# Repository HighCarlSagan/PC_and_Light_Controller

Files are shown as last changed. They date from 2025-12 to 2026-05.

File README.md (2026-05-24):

# PC & Light Controller







A single-board ESP32 controller that remotely actuates a PC's UPS power button via servo and switches three 5 V LED lighting channels via eFuses — all driven from a Telegram bot. Part of a larger homelab automation setup.

<p align="center">
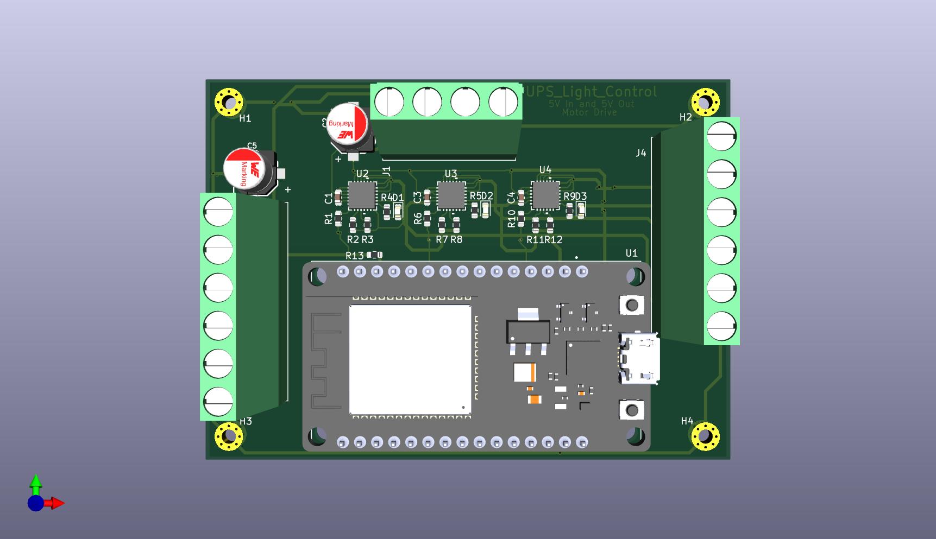
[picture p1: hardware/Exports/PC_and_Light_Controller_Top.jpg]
PCB top render
  
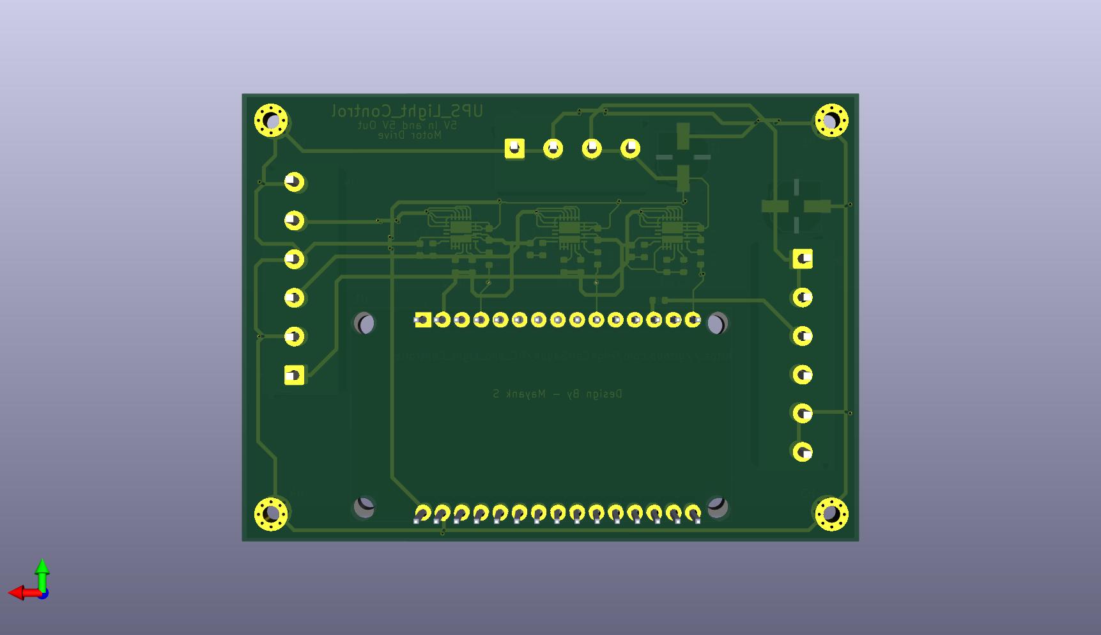
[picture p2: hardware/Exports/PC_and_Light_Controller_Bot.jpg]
PCB bottom render
  
</p>

---

## Why I Built This

I needed a physical "finger" to press the UPS power button on my desk so I could wake the PC from anywhere — usually while travelling, sometimes just from another room — without opening the UPS chassis (which would void warranty) and without buying a generic smart-plug solution that wouldn't fit cleanly into the rest of my homelab.

This board is the missing piece in a longer chain: once the UPS is on, my homelab handles the rest — Wake-on-LAN brings up the PC, Tailscale + SSH let me into the machine, and Home Assistant takes care of the rest of the room. The UPS button was the one stubbornly physical step left, and the LEDs were a natural extension once I had an ESP32 sitting there with spare GPIOs and a free 5 V rail.

A few things I deliberately wanted out of the project:

- **Telegram bot integration without port forwarding** — the ESP32 polls outbound, no inbound ports exposed
- **No new cloud dependency beyond Telegram** — everything else stays local to the homelab
- **Clean integration with my existing 5 V/3.3 V bench supply** — no extra wall-warts
- **A learning project for ESP32 + eFuse load switching** — TPS259807 with proper ILIM configuration

---

## Initial Requirements

| # | Requirement | Target | Outcome |
|---|---|---|---|
| 1 | UPS power-button actuation | Non-invasive, preserves warranty | Servo-actuated push (no electrical mod to UPS) |
| 2 | LED channels | 3 independently switched 5 V loads | 3× TPS259807 eFuse channels |
| 3 | Per-channel current | ≥ 0.5 A per channel | ILIM set to 1 A per channel (headroom) |
| 4 | Remote control | Internet-reachable, no port forwarding | Outbound Telegram bot polling |
| 5 | Security | Only authorized user can issue commands | Chat ID allowlist verification |
| 6 | Homelab integration | Works alongside WoL + SSH workflow | Sits as the "physical actuator" tier |
| 7 | Power | Powered from existing dual-rail bench PSU | Single 5 V input |
| 8 | MCU count | Single board, single MCU | One ESP32 DevKit V1 doing both jobs |
| 9 | Variable per-channel current limit | Set in firmware/UI | **V1 has fixed 1 A** — V2 will use software-trim ILIM |
| 10 | Local fallback (LAN-only mode) | Optional | Not in V1 — Telegram-only for now |

---

## Specifications

| Parameter | Value |
|---|---|
| MCU | ESP32 DevKit V1 (ESP-WROOM-32) |
| Input voltage | 5 V DC |
| Light channels | 3× TPS259807 eFuse, ILIM = 1 A each |
| Servo output | 1× PWM (5 V tolerant) |
| Status indicators | 3× per-channel LEDs |
| PCB | 2-layer FR-4, 1.6 mm |
| Connectors | 1× 4-pin power input, 2× 6-pin output blocks |
| Mounting | 4× corner holes |
| Communication | WiFi 802.11 b/g/n + outbound HTTPS to Telegram |

---

## Architecture

```
                                   ┌──────────────────┐
   Telegram Cloud  ◀──HTTPS poll──▶│   ESP32 DevKit   │
                                   │   (single MCU)   │
                                   └──┬─────┬─────┬───┘
                                      │     │     │
            GPIO ──────┬───────┬──────┘     │     │
                       │       │            │     │
                  ┌────▼─┐ ┌───▼──┐ ┌───────▼──┐  │
                  │ EN1  │ │ EN2  │ │   EN3    │  │  PWM
                  │TPS1  │ │TPS2  │ │   TPS3   │  │   │
                  │259807│ │259807│ │  259807  │  │   ▼
                  └──┬───┘ └──┬───┘ └────┬─────┘  │  Servo
                     │        │          │        │   │
                  Light 1  Light 2    Light 3     │   ▼
                                                  │  UPS button
                                                  └─ (mechanical press)
```

A single ESP32 polls the Telegram bot every ~1 second, parses incoming commands, and dispatches to either:

- **GPIO outputs** driving the EN pins of three TPS259807 eFuses (light channels), or
- **A PWM channel** driving a servo whose horn physically presses the UPS power button.

Per-channel status LEDs reflect the current state of each light. A chat-ID allowlist in firmware ensures only authorized users can issue commands.

---

## Why a Servo for the UPS Button?

This is the unusual design choice and worth calling out: most projects that automate a button-press would either tap directly across the button contacts with a transistor, or use a relay. Both work — neither was acceptable here.

The UPS is still under warranty. Opening it to solder anything across the button contacts would void that. A servo with a 3D-printed horn pressing the button externally is fully non-invasive — the UPS sees nothing electrically unusual, the warranty stays intact, and the same approach generalizes to any push-button I might want to actuate later (microwave, doorbell, whatever). It's a slightly larger mechanical solution, but mechanically and electrically clean.

---

## Key Components

| Reference | Part | Function |
|---|---|---|
| U1 | ESP32 DevKit V1 | WiFi + dual-core MCU, both controllers in one |
| U2, U3, U4 | TI TPS259807ONRGER | 5 V eFuse load switches with adjustable current limit |
| D1, D2, D3 | LEDs (0603) | Per-channel status indicators |
| C2, C5 | 100 µF / 16 V | Bulk decoupling on input + output |
| C1, C3, C4 | 0.1 µF / 16 V | Local decoupling at each TPS259807 |
| R1/R6/R10 | 220 Ω | LED current limiting |
| R2/R7/R11 | 298 Ω | TPS259807 ILIM resistor (sets ~1 A current limit) |
| R3/R8/R12 | 10 kΩ | TPS259807 EN pull-down |
| R4/R5/R9/R13 | 1 kΩ | GPIO series resistors / servo signal |
| J1 | 4-pin screw terminal | 5 V power input from external PSU |
| J3, J4 | 6-pin screw terminals | Light output channels + servo header |

---

## Connector Pinout

| Connector | Function |
|---|---|
| J1 | 5 V input from external PSU (V+, V+, GND, GND) |
| J3 | Light outputs (channels 1–3) — V+ and GND pairs per channel |
| J4 | Servo header + auxiliary outputs |

> Detailed pin-by-pin assignments are on the PCB silkscreen and in `hardware/Exports/schematic.pdf`.

---

## Firmware

### Architecture

Single firmware image runs on one ESP32 and serves both the UPS-press and lights-switching commands. Internally the code is split into two logical modules under separate folders so the unit-tests stay focused, but only one binary gets flashed.

| Layer | Library / Framework |
|---|---|
| Build system | PlatformIO |
| Framework | Arduino-ESP32 |
| Networking | WiFi.h + WiFiClientSecure |
| Telegram client | UniversalTelegramBot |
| Servo control | ESP32Servo |
| JSON parsing | ArduinoJson |

### Command interface

Commands are split by prefix so both function groups remain logically separate:

**UPS commands** (servo actuation):
- `/ups_press` — Press the UPS power button
- `/ups_status` — Get controller status
- `/ups_help` — Show help

**Lights commands**:
- `/lights_<n>_on`, `/lights_<n>_off` — Control individual light (n = 1, 2, 3)
- `/lights_all_on`, `/lights_all_off` — Bulk control
- `/lights_status` — Report current state of all channels
- `/lights_help` — Show help

Full command reference: [`docs/commands/TELEGRAM_COMMANDS.md`](docs/commands/TELEGRAM_COMMANDS.md)

### Security

- **Chat ID allowlist** — only pre-registered Telegram chat IDs are honored, all others ignored
- **Outbound-only networking** — no inbound ports, no port forwarding, no exposed services on the LAN
- **TLS to Telegram** — all command traffic over HTTPS
- **Secrets isolation** — WiFi credentials, bot token, and chat IDs live in `secrets.h`, gitignored, with an `.example` template committed

### Repository layout for firmware

```
firmware/
├── ups-controller/                 # UPS servo logic (build target 1)
│   ├── include/
│   │   ├── config.h                # Pin assignments, timing constants
│   │   ├── secrets.h               # GITIGNORED — actual credentials
│   │   └── secrets.h.example       # Template
│   ├── src/main.cpp
│   └── platformio.ini
└── lights-controller/              # LED switching logic (build target 2)
    ├── include/                    # Same structure as above
    ├── src/main.cpp
    └── platformio.ini
```

> The two folders compile to two separate firmware images in the V1 development setup. For deployment, both feature sets will be merged into a single combined firmware image for the production ESP32 — that consolidation is part of the deployment step.

---

## Setup & Deployment

> **Status:** PCB delivered, awaiting assembly. Step-by-step setup will be added here once the board is soldered, flashed, and deployed in the rack.

This section will cover:

1. Bill of materials acquisition
2. SMD + through-hole assembly notes
3. ESP32 first-flash procedure
4. Telegram bot creation (BotFather workflow)
5. Configuring `secrets.h` (WiFi, bot token, chat ID allowlist)
6. Initial bringup test sequence (status LED check, channel-by-channel test, servo calibration)
7. Mounting and mechanical alignment of the servo to the UPS button
8. Integration into the homelab rack and final cabling

---

## Testing

> Test results will be added in `docs/images/` and a summary table here once bringup is complete.

### Planned bringup test sequence

| Step | Test | Pass criteria |
|---|---|---|
| 1 | Visual inspection | No solder bridges, all parts present, polarized parts oriented correctly |
| 2 | Power-on, no firmware | 5 V rail clean, no smoke, current draw < 50 mA at idle |
| 3 | Firmware flash | ESP32 enumerates, serial console prints boot banner |
| 4 | WiFi association | Connects to configured SSID, IP assigned |
| 5 | Telegram heartbeat | Bot responds to `/lights_help` and `/ups_help` |
| 6 | Light channel test (no load) | Each EN GPIO toggles its eFuse; status LED follows; no output current with no load attached |
| 7 | Light channel test (with load) | Each channel drives an LED strip up to ~0.5 A; status LED on; eFuse cool |
| 8 | Light channel overcurrent test | Force ~1.2 A on one channel, eFuse trips, channel recovers after re-enable |
| 9 | Servo sweep | Manual `/ups_press` triggers full press-and-release cycle, audible click on UPS |
| 10 | Soak test | All three lights on + occasional servo press, 1 hour, no thermal issues |

### Results

*To be filled in after bringup.*

---

## Hardware

### PCB

- 2-layer FR-4
- 1.6 mm thickness
- 1 oz copper
- ENIG or HASL lead-free
- Designed in KiCad 9.0
- Compatible with JLCPCB, PCBWay, OSHPark, etc.

### Manufacturing files

- Gerbers + drill files: [`hardware/Exports/Gerbers/`](hardware/Exports/Gerbers/)
- Zipped gerbers (drag-and-drop into fab portals): `hardware/Exports/pc_and_light_controller_gerbers.zip`
- Interactive BOM: `hardware/Exports/ibom.html`
- BOM CSV: `hardware/Exports/UPS_Switch_BoM.csv`
- Schematic PDF: `hardware/Exports/schematic.pdf`

---

## Repository Structure

```
PC_and_Light_Controller/
├── docs/
│   ├── commands/
│   │   └── TELEGRAM_COMMANDS.md         # Full command reference
│   ├── Flashing_Guide_Mini.md           # ESP32 flash quick reference
│   ├── images/                          # Photos & screenshots
│   └── pinout.ini                       # Pin assignment reference
├── firmware/
│   ├── ups-controller/                  # Servo / UPS button firmware module
│   └── lights-controller/               # Lights / eFuse firmware module
├── hardware/
│   ├── Exports/                         # Gerbers, BOM, renders, schematic
│   ├── Libraries/                       # Custom KiCad symbols, footprints, 3D models
│   ├── PC_and_Light_Controller.kicad_pro
│   ├── PC_and_Light_Controller.kicad_sch
│   └── PC_and_Light_Controller.kicad_pcb
├── enclosure/
│   └── docs/                            # FreeCAD / Blender enclosure work
├── LICENSE
└── README.md
```

---

## When to Use This

**Good fit:**
- Remote-pressing a physical button you can't or won't open
- Switching small 5 V DC loads (LED strips, fans, low-power lighting) with overcurrent protection
- Building blocks for a homelab automation tier where outbound-only networking is desired
- A learning vehicle for ESP32 + Telegram + eFuse load switching

**Not a good fit:**
- Mains-voltage switching (use a proper relay board with isolation)
- High-current loads above ~1 A per channel (the V1 ILIM cap)
- Time-critical control where ~1 second polling latency matters
- Air-gapped networks (V1 is Telegram-dependent — V2 will add a local-only path)

---

## Roadmap

### V1 (current)
- ✅ Hardware design complete
- ✅ Firmware logic written and tested on dev boards
- 🔄 PCB assembly pending
- 🔄 First-deployment bringup pending

### V2 wishlist
- Variable per-channel current limit (digitally trimmable ILIM)
- Local-only control path (MQTT to homelab broker, Telegram becomes one of multiple frontends)
- Per-channel current measurement (INA-class shunt monitor) for telemetry back to homelab
- Combined unified firmware image instead of two-folder dev split
- Onboard 5 V regulation so the board can be powered from a wider input range
- Status display (small OLED) showing channel state and last command

---

## Security Note

This board exists inside a private homelab network and is gated by a Telegram chat-ID allowlist. As deployed:

- Network-side identifiers (SSID, IPs, MACs) are intentionally **not** committed to this repo
- All credentials live in `secrets.h` files which are gitignored — only `.example` templates ship
- The Telegram bot token is the principal credential; treat it like a password

If you fork this and deploy it on your own network, replace every value in `secrets.h.example` with your own and never commit a real `secrets.h`.

---

## License

- **Hardware**: [CERN-OHL-P-2.0](LICENSE) (Permissive)
- **Firmware**: MIT

---

## Related Projects

- [Dual_Power_Supply](https://github.com/HighCarlSagan/Dual_Power_Supply) — provides the 5 V rail that powers this board
- [Carls_Homelab](https://github.com/HighCarlSagan/Carls_Homelab) — the rest of the homelab stack this integrates with

---

## Author

**Mayank S (HighCarlSagan)** — [GitHub @HighCarlSagan](https://github.com/HighCarlSagan) · [highcarlsagan.dev](https://highcarlsagan.dev)

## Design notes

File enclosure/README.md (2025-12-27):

# Enclosure Design

FreeCAD designs for the PC & Light Controller enclosure.

## Files

- `freecad/` - FreeCAD project files (.FCStd)
- `stl/` - 3D printable STL files
- `step/` - STEP files for CNC/sharing
- `docs/` - Assembly instructions, dimensions

## Design Requirements

- Mount for custom PCB
- Cutouts for:
  - Power input connector
  - 3x LED output connectors
  - Motor output connector
  - USB programming port (ESP32)
- Ventilation for components
- Mounting holes for installation

## Printing Settings

TBD - will update after first prototype

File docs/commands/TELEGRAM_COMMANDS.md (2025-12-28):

# Telegram Bot Commands

This document lists all available commands for the PC & Light Controller Telegram bot.

## Bot Information
- **Bot Name:** [Your bot name]
- **Bot Username:** @[your_bot_username]
- **Security:** Only responds to authorized Chat ID

## UPS Controller Commands

Control the UPS power button via servo motor.

| Command | Description |
|---|---|
| `/ups_press` | Press the UPS power button (servo activates for 500ms) |
| `/ups_status` | Get UPS controller status (WiFi, IP, servo state) |
| `/ups_help` | Show UPS controller help |

**Example Usage:**
```
/ups_press
```
Response: `✅ UPS button pressed!`

---

## Lights Controller Commands

Control 3 LED light switches.

### Individual Light Control

| Command | Description |
|---|---|
| `/lights_1_on` | Turn Light 1 ON |
| `/lights_1_off` | Turn Light 1 OFF |
| `/lights_2_on` | Turn Light 2 ON |
| `/lights_2_off` | Turn Light 2 OFF |
| `/lights_3_on` | Turn Light 3 ON |
| `/lights_3_off` | Turn Light 3 OFF |

### Bulk Control

| Command | Description |
|---|---|
| `/lights_all_on` | Turn all lights ON |
| `/lights_all_off` | Turn all lights OFF |

### Status & Help

| Command | Description |
|---|---|
| `/lights_status` | Get status of all lights + WiFi info |
| `/lights_help` | Show lights controller help |

**Example Usage:**
```
/lights_1_on
```
Response: `✅ Light 1 ON`
```
/lights_status
```
Response:
```
💡 Lights Status:
Light 1: ON ✓
Light 2: OFF
Light 3: OFF
WiFi: Connected ✓
IP: 192.168.0.84
```

---

## How It Works

### Architecture
- **One Telegram Bot** controls both ESP32 devices
- **Command Prefixes** determine which ESP32 responds:
  - `/ups_*` → UPS Controller ESP32
  - `/lights_*` → Lights Controller ESP32
- Each ESP32 ignores commands not meant for it

### Security
- Only authorized Chat ID can send commands
- Unauthorized users receive "⛔ Unauthorized access" message
- All commands are logged to serial monitor

### Response Time
- Commands are checked every 1 second (polling interval)
- Typical response time: 1-2 seconds

---

## Troubleshooting

**Bot not responding:**
1. Check ESP32 is powered on
2. Check WiFi connection (LED should be solid ON)
3. Check serial monitor for errors
4. Verify bot token and chat ID in `secrets.h`

**Wrong device responding:**
- Check command prefix (`/ups_` vs `/lights_`)
- Each ESP32 only responds to its prefix

**Unauthorized access message:**
- Verify your Chat ID matches the one in `secrets.h`
- Get your Chat ID from @userinfobot

---

## Adding More Devices

To add another ESP32 device:

1. Choose a new command prefix (e.g., `/garage_`)
2. Create new firmware folder
3. Use same bot token and chat ID
4. Check for prefix in `handleNewMessages()`

Example for garage door:
```cpp
if (!text.startsWith("/garage_")) {
  return; // Ignore
}
```

---

## Notes

- Both ESP32s use the **same WiFi network**
- Both ESP32s use the **same Telegram bot**
- Commands work from anywhere in the world (via Telegram)
- No port forwarding required
- No separate server needed

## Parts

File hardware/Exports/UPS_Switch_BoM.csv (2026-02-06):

Reference | Qty | Value | DNP | Exclude from BOM | Exclude from Board | Footprint | Datasheet | Manufacturer | Price | Description | Manufacturer Part Number | Vendor | Vendor Link | Vendor Part Number
C1,C3,C4 | 3 | 0.1u_16V_0603 |  |  |  | Capacitor_SMD:C_0603_1608Metric | https://www.yageo.com/en/Chart/Download/pdf/CC0603KRX7R7BB104 | YAGEO | 7 | 0.1 µF ±10% 16V Ceramic Capacitor X7R 0603 (1608 Metric) | CC0603KRX7R7BB104 |  | https://www.digikey.in/en/products/detail/yageo/CC0603KRX7R7BB104/302822 | 311-1088-1-ND
C2,C5 | 2 | 100u_16V_0603 |  |  |  | ESP32_Devkit_V1:WCAP-ASLI_6.3X5.5_DXL_ | https://www.we-online.com/components/products/datasheet/865080343009.pdf | Würth Elektronik | 24 | 100 µF 16 V Aluminum Electrolytic Capacitors Radial, Can - SMD 2000 Hrs @ 105°C | 865080343009 |  | https://www.digikey.in/en/products/detail/w%C3%BCrth-elektronik/865080343009/5728014 | 732-8419-1-ND
D1,D2,D3 | 3 | LED |  |  |  | LED_SMD:LED_0603_1608Metric | ~ |  |  | Light emitting diode
H1,H2,H3,H4 | 4 | MountingHole_Pad |  | Excluded from BOM |  | MountingHole:MountingHole_2.2mm_M2_Pad_Via | ~ |  |  | Mounting Hole with connection
J1 | 1 | Screw_Terminal_01x04 |  |  |  | TerminalBlock_Phoenix:TerminalBlock_Phoenix_MKDS-1,5-4-5.08_1x04_P5.08mm_Horizontal | ~ |  |  | Generic screw terminal, single row, 01x04, script generated (kicad-library-utils/schlib/autogen/connector/)
J3,J4 | 2 | Screw_Terminal_01x06 |  |  |  | TerminalBlock_Phoenix:TerminalBlock_Phoenix_MKDS-1,5-6-5.08_1x06_P5.08mm_Horizontal | ~ |  |  | Generic screw terminal, single row, 01x06, script generated (kicad-library-utils/schlib/autogen/connector/)
R1,R6,R10 | 3 | 220R_0.21W_0603 |  |  |  | Resistor_SMD:R_0603_1608Metric | https://www.te.com/usa-en/product-2176177-3.datasheet.pdf | TE Connectivity Passive Product | 8 | 220 Ohms ±1% 0.2W, 1/5W Chip Resistor 0603 (1608 Metric) Automotive AEC-Q200 Thick Film | CRGH0603F220R |  | https://www.digikey.in/en/products/detail/te-connectivity-passive-product/CRGH0603F220R/7495060 | 1712-CRGH0603F220RCT-ND
R2,R7,R11 | 3 | 298R_0.21W_0603 |  |  |  | Resistor_SMD:R_0603_1608Metric | https://industrial.panasonic.com/cdbs/www-data/pdf/RDM0000/AOA0000C328.pdf | Panasonic Electronic Components | 14 | 300 Ohms ±0.1% 0.2W, 1/5W Chip Resistor 0603 (1608 Metric) Automotive AEC-Q200 Thick Film | ERJ-PB3B3000V |  | https://www.digikey.in/en/products/detail/panasonic-electronic-components/ERJ-PB3B3000V/6212693 | P19910CT-ND
R3,R8,R12 | 3 | 10k_0.1W_0603 |  |  |  | Resistor_SMD:R_0603_1608Metric | https://industrial.panasonic.com/cdbs/www-data/pdf/RDM0000/AOA0000C328.pdf | Panasonic Electronic Components | 14 | 10 kOhms ±0.1% 0.2W, 1/5W Chip Resistor 0603 (1608 Metric) Automotive AEC-Q200 Thick Film | ERJ-PB3B1002V |  | https://www.digikey.in/en/products/detail/panasonic-electronic-components/ERJ-PB3B1002V/6212869 | P20086CT-ND
R4,R5,R9,R13 | 4 | 1k_0.2W_0603 |  |  |  | Resistor_SMD:R_0603_1608Metric | https://industrial.panasonic.com/cdbs/www-data/pdf/RDM0000/AOA0000C328.pdf | Panasonic Electronic Components | 14 | 1 kOhms ±0.1% 0.2W, 1/5W Chip Resistor 0603 (1608 Metric) Automotive AEC-Q200 Thick Film | ERJ-PB3B1001V |  | https://www.digikey.in/en/products/detail/panasonic-electronic-components/ERJ-PB3B1001V/6212755 | P19972CT-ND
U1 | 1 | ESP32-DEVKIT-V1 |  |  |  | Footprints:MODULE_ESP32_DEVKIT_V1 |  | Jellybean | 400 | ESP32 Devkit Module |  |  | https://robu.in/product/esp32-38pin-development-board-wifibluetooth-ultra-low-power-consumption-dual-core/ | ESP32-DEVKIT-V1
U2,U3,U4 | 3 | TPS259807ONRGER |  |  |  | TPS25980_footprints:VQFN24_RGE_TEX | https://www.ti.com/lit/gpn/tps25980 | Texas Instruments | 196 | Hot Swap Controller 1 Channel General Purpose 24-VQFN (4x4) | TPS259807ONRGER |  | https://www.digikey.com/en/products/detail/texas-instruments/TPS259807ONRGER/13174056 | 296-TPS259807ONRGERCT-ND

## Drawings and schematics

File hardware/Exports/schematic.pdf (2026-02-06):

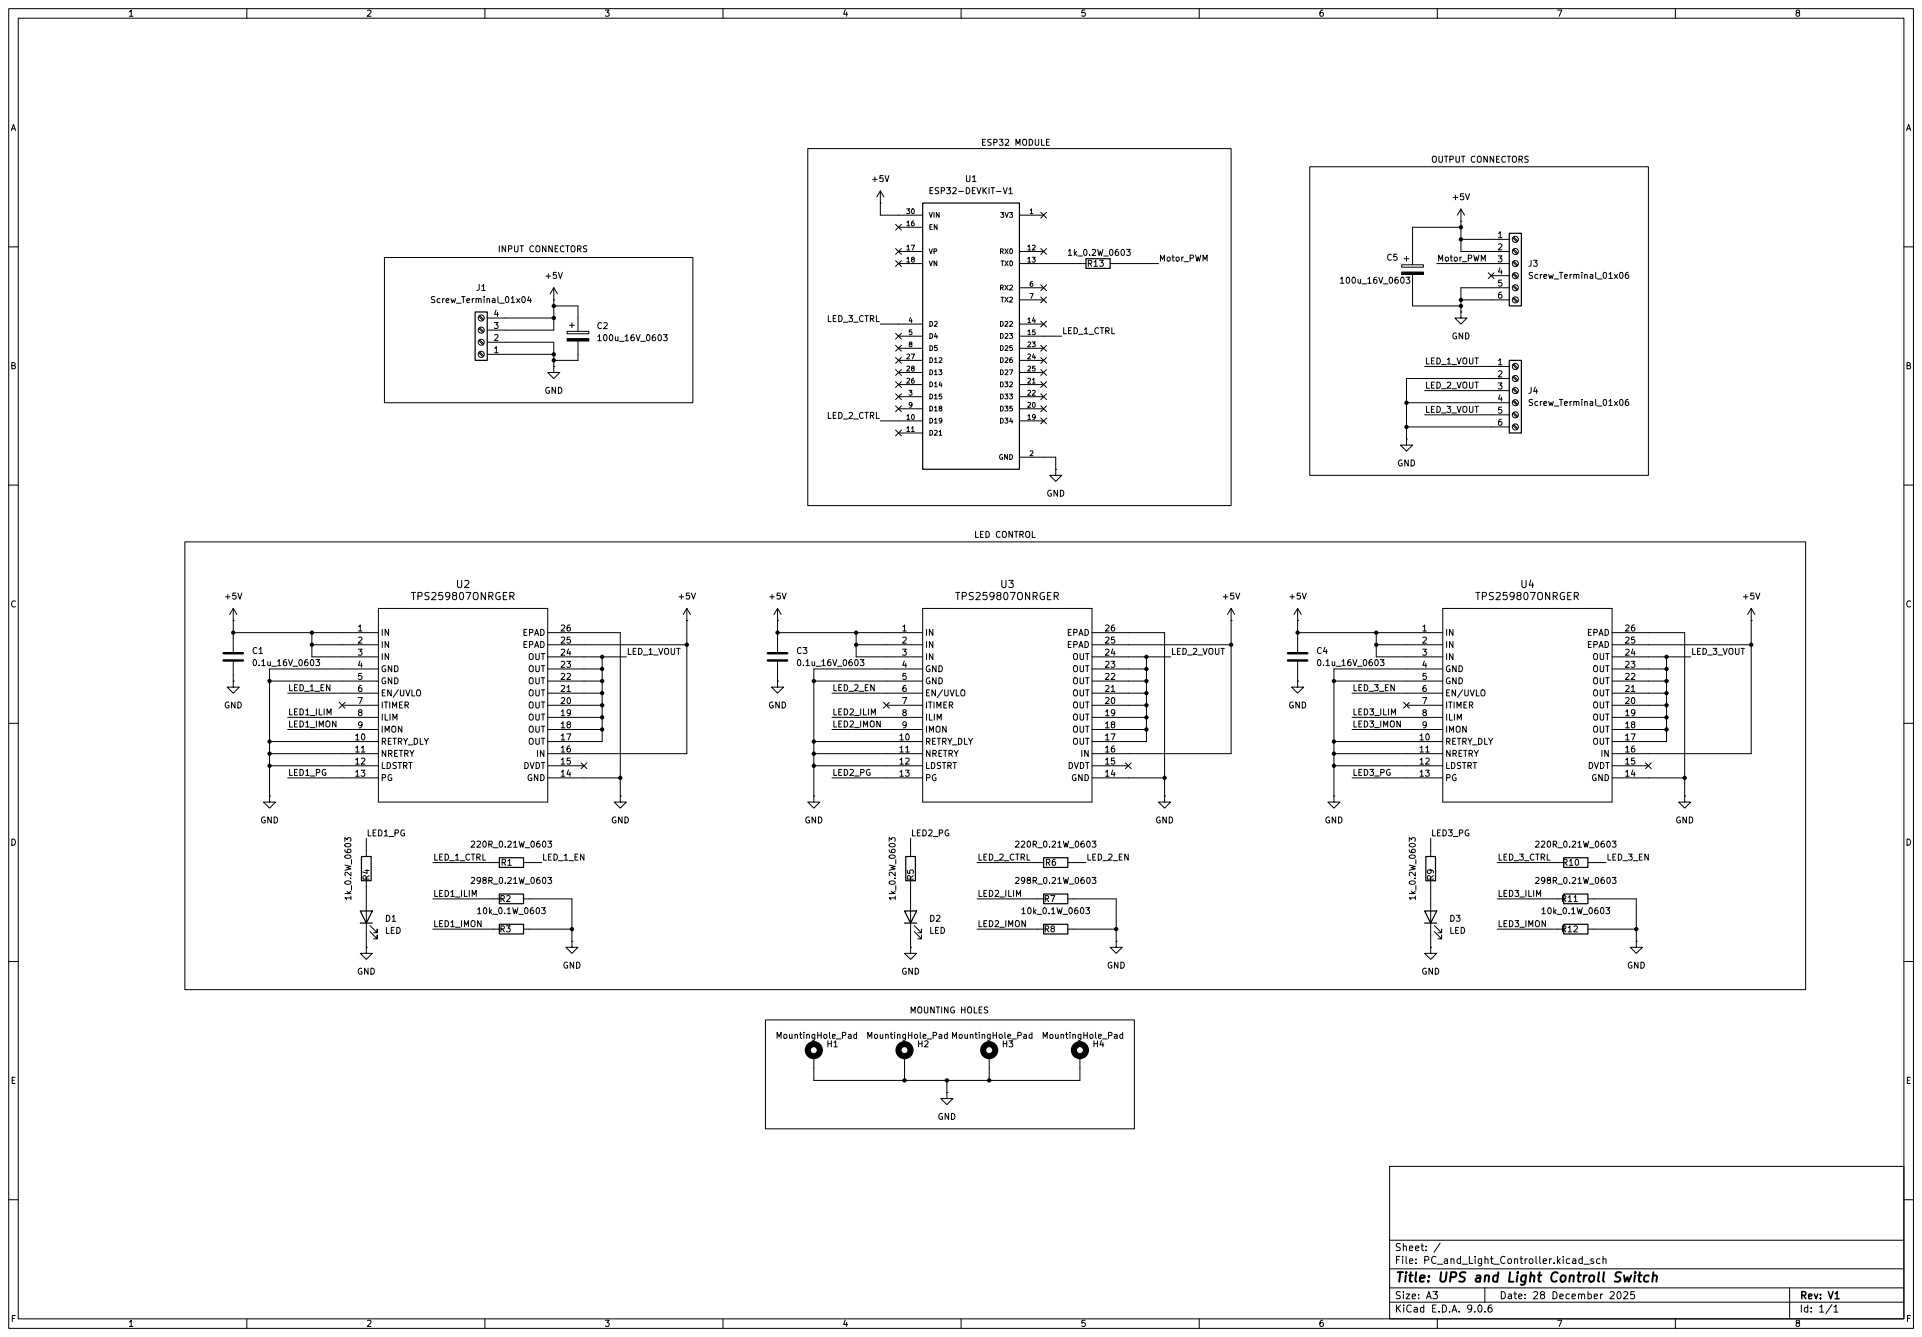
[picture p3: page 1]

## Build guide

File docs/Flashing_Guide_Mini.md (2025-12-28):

ESP32 QUICK FLASH GUIDE - PC & LIGHT CONTROLLER
================================================

HARDWARE SETUP
--------------
ESP32 #1: "UPS"     → Controls servo motor (GPIO 13)
ESP32 #2: "LIGHTS"  → Controls 3 switches (GPIO 25, 26, 27)

Both use:
- WiFi: WIFI_SSID
- Same Telegram bot token
- Same Chat ID: 408698756

FLASH ESP32 #1 (UPS CONTROLLER)
--------------------------------

1. Label board with "UPS" (permanent marker)

2. Connect USB and verify
   lsusb | grep CP210
   ls /dev/ttyUSB*

3. Navigate to firmware
   cd ~/Projects/Hardware/PC_and_Light_Controller/firmware/ups-controller

4. Verify secrets.h exists
   cat include/secrets.h
   (Should show WiFi credentials, bot token, chat ID)

5. Compile and upload
   pio run --target clean
   pio run --target upload
   HOLD BOOT button when you see "Connecting..."

6. Monitor output
   pio device monitor

   Expected output:
   === UPS Controller - Telegram Bot ===
   ✓ Servo initialized
   ✓ WiFi connected!
   IP address: 192.168.0.XX  ← Note this down
   Listening for /ups_ commands...

7. Test from Telegram
   Send: /ups_help
   Should get command list reply

8. Unplug ESP32 #1

FLASH ESP32 #2 (LIGHTS CONTROLLER)
-----------------------------------

1. Label board with "LIGHTS"

2. Connect USB (ESP32 #1 should be unplugged)
   lsusb | grep CP210

3. Navigate to firmware
   cd ~/Projects/Hardware/PC_and_Light_Controller/firmware/lights-controller

4. Verify secrets.h (copy from UPS if missing)
   cat include/secrets.h

5. Compile and upload
   pio run --target clean
   pio run --target upload
   HOLD BOOT when "Connecting..."

6. Monitor output
   pio device monitor

   Expected output:
   === Lights Controller - Telegram Bot ===
   ✓ LED pins initialized
   ✓ WiFi connected!
   IP address: 192.168.0.YY  ← Note this down
   Listening for /lights_ commands...

7. Test from Telegram
   Send: /lights_help
   Should get command list reply

TEST BOTH TOGETHER
------------------

1. Plug in both ESP32s (via USB or 5V power)

2. Test command isolation
   Send: /ups_press      → Only UPS responds
   Send: /lights_1_on    → Only Lights responds

   ✅ Each ESP32 ignores commands not meant for it

TROUBLESHOOTING
---------------

Upload fails (Connecting......):
  Hold BOOT button on ESP32 during upload
  Or: sudo chmod 666 /dev/ttyUSB0

WiFi won't connect:
  Check secrets.h has correct credentials
  Verify WiFi is 2.4GHz (ESP32 doesn't do 5GHz)
  Move ESP32 closer to router

Serial monitor shows garbage:
  pio device monitor -b 115200

Bot not responding:
  Verify Chat ID is 408698756 in secrets.h
  Verify bot token is correct
  Check serial monitor for "Unauthorized user"

QUICK REFERENCE
---------------

Check USB:        lsusb | grep CP210
UPS firmware:     cd ~/Projects/.../firmware/ups-controller
Lights firmware:  cd ~/Projects/.../firmware/lights-controller
Upload:           pio run --target upload (hold BOOT)
Monitor:          pio device monitor (Ctrl+C to exit)

CONFIGURATION RECORD
--------------------

ESP32 #1 (UPS):
  IP Address: _______________
  Commands: /ups_press, /ups_status, /ups_help
  GPIO: 13 (Servo)

ESP32 #2 (Lights):
  IP Address: _______________
  Commands: /lights_1_on, /lights_all_off, /lights_status
  GPIO: 25, 26, 27 (Switches)

WHAT'S NEXT
-----------

1. ✅ Both ESP32s flashed and tested
2. Get servo motor (SG90) and test with /ups_press
3. Get TPS259807 chips for actual switch control
4. Design PCBs in KiCad
5. Order and assemble custom boards

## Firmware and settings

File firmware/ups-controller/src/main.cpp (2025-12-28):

#include <Arduino.h>
#include <WiFi.h>
#include <WiFiClientSecure.h>
#include <UniversalTelegramBot.h>
#include <ESP32Servo.h>
#include "config.h"
#include "secrets.h"

// Function declarations
void handleNewMessages(int numNewMessages);
void pressButton();

// WiFi and Telegram
WiFiClientSecure secured_client;
UniversalTelegramBot bot(BOT_TOKEN, secured_client);

// Servo
Servo upsServo;

// Timing
unsigned long lastBotCheck = 0;

// State
bool isPressed = false;

void setup() {
  Serial.begin(115200);
  delay(1000);
  Serial.println("\n\n=== UPS Controller - Telegram Bot ===");
  
  // Setup pins
  pinMode(STATUS_LED, OUTPUT);
  digitalWrite(STATUS_LED, LOW);
  
  // Attach servo
  upsServo.attach(SERVO_PIN);
  upsServo.write(SERVO_REST_ANGLE);
  Serial.println("✓ Servo initialized at rest position");
  
  // Connect to WiFi
  Serial.print("Connecting to WiFi: ");
  Serial.println(WIFI_SSID);
  WiFi.begin(WIFI_SSID, WIFI_PASSWORD);
  
  while (WiFi.status() != WL_CONNECTED) {
    delay(500);
    Serial.print(".");
  }
  
  Serial.println("\n✓ WiFi connected!");
  Serial.print("IP address: ");
  Serial.println(WiFi.localIP());

  // Skip SSL certificate validation
  secured_client.setInsecure();
  
  // Configure SSL certificate (for Telegram)
  // secured_client.setCACert(TELEGRAM_CERTIFICATE_ROOT);
  
  Serial.println("✓ Telegram bot ready");
  Serial.println("Authorized Chat ID: " + String(CHAT_ID));
  Serial.println("\nListening for /ups_ commands...\n");
  
  // LED on = ready
  digitalWrite(STATUS_LED, HIGH);
}

void loop() {
  // Check for new messages every BOT_CHECK_INTERVAL
  if (millis() - lastBotCheck > BOT_CHECK_INTERVAL) {
    int numNewMessages = bot.getUpdates(bot.last_message_received + 1);
    
    while (numNewMessages) {
      handleNewMessages(numNewMessages);
      numNewMessages = bot.getUpdates(bot.last_message_received + 1);
    }
    
    lastBotCheck = millis();
  }
}

void handleNewMessages(int numNewMessages) {
  for (int i = 0; i < numNewMessages; i++) {
    String chat_id = String(bot.messages[i].chat_id);
    String text = bot.messages[i].text;
    String from_name = bot.messages[i].from_name;
    
    Serial.println("Message from: " + from_name + " (" + chat_id + ")");
    Serial.println("Text: " + text);
    
    // Security: Only respond to authorized user
    if (chat_id != CHAT_ID) {
      Serial.println("⚠️  Unauthorized user! Ignoring.");
      bot.sendMessage(chat_id, "⛔ Unauthorized access");
      continue;
    }
    
    // Only process commands starting with /ups_
    if (!text.startsWith("/ups_")) {
      Serial.println("Not for UPS controller, ignoring.");
      continue;
    }
    
    // Blink LED to show processing
    digitalWrite(STATUS_LED, LOW);
    delay(100);
    digitalWrite(STATUS_LED, HIGH);
    
    // Process commands
    if (text == "/ups_press") {
      pressButton();
      bot.sendMessage(chat_id, "✅ UPS button pressed!");
      
    } else if (text == "/ups_status") {
      String status = "🔌 UPS Controller Status:\n";
      status += "WiFi: Connected ✓\n";
      status += "IP: " + WiFi.localIP().toString() + "\n";
      status += "Servo: " + String(isPressed ? "Pressed" : "Rest") + "\n";
      bot.sendMessage(chat_id, status);
      
    } else if (text == "/ups_help") {
      String help = "🤖 UPS Controller Commands:\n\n";
      help += "/ups_press - Press UPS button\n";
      help += "/ups_status - Get status\n";
      help += "/ups_help - Show this help";
      bot.sendMessage(chat_id, help);
      
    } else {
      bot.sendMessage(chat_id, "❓ Unknown command. Try /ups_help");
    }
    
    Serial.println("✓ Command processed\n");
  }
}

void pressButton() {
  Serial.println("→ Pressing UPS button...");
  
  isPressed = true;
  upsServo.write(SERVO_PRESS_ANGLE);
  delay(PRESS_DURATION);
  
  upsServo.write(SERVO_REST_ANGLE);
  isPressed = false;
  
  Serial.println("→ Button released");
}

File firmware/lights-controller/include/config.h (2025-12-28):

#ifndef CONFIG_H
#define CONFIG_H

// Pin Definitions
#define LED1_PIN 25
#define LED2_PIN 26
#define LED3_PIN 27
#define STATUS_LED 2

// Telegram Settings
#define BOT_CHECK_INTERVAL 1000  // Check for messages every 1 second

#endif

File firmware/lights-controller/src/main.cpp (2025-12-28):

#include <Arduino.h>
#include <WiFi.h>
#include <WiFiClientSecure.h>
#include <UniversalTelegramBot.h>
#include "config.h"
#include "secrets.h"

// Function declarations
void handleNewMessages(int numNewMessages);
void setLED(int channel, bool state);

// WiFi and Telegram
WiFiClientSecure secured_client;
UniversalTelegramBot bot(BOT_TOKEN, secured_client);

// Timing
unsigned long lastBotCheck = 0;

// LED States
bool led1State = false;
bool led2State = false;
bool led3State = false;

void setup() {
  Serial.begin(115200);
  delay(1000);
  Serial.println("\n\n=== Lights Controller - Telegram Bot ===");
  
  // Setup pins
  pinMode(STATUS_LED, OUTPUT);
  pinMode(LED1_PIN, OUTPUT);
  pinMode(LED2_PIN, OUTPUT);
  pinMode(LED3_PIN, OUTPUT);
  
  // All off initially
  digitalWrite(STATUS_LED, LOW);
  digitalWrite(LED1_PIN, LOW);
  digitalWrite(LED2_PIN, LOW);
  digitalWrite(LED3_PIN, LOW);
  
  Serial.println("✓ LED pins initialized");
  
  // Connect to WiFi
  Serial.print("Connecting to WiFi: ");
  Serial.println(WIFI_SSID);
  WiFi.begin(WIFI_SSID, WIFI_PASSWORD);
  
  while (WiFi.status() != WL_CONNECTED) {
    delay(500);
    Serial.print(".");
  }
  
  Serial.println("\n✓ WiFi connected!");
  Serial.print("IP address: ");
  Serial.println(WiFi.localIP());
  
  // Skip SSL certificate validation
  secured_client.setInsecure();
  
  Serial.println("✓ Telegram bot ready");
  Serial.println("Authorized Chat ID: " + String(CHAT_ID));
  Serial.println("\nListening for /lights_ commands...\n");
  
  // LED on = ready
  digitalWrite(STATUS_LED, HIGH);
}

void loop() {
  // Check for new messages every BOT_CHECK_INTERVAL
  if (millis() - lastBotCheck > BOT_CHECK_INTERVAL) {
    int numNewMessages = bot.getUpdates(bot.last_message_received + 1);
    
    while (numNewMessages) {
      handleNewMessages(numNewMessages);
      numNewMessages = bot.getUpdates(bot.last_message_received + 1);
    }
    
    lastBotCheck = millis();
  }
}

void handleNewMessages(int numNewMessages) {
  for (int i = 0; i < numNewMessages; i++) {
    String chat_id = String(bot.messages[i].chat_id);
    String text = bot.messages[i].text;
    String from_name = bot.messages[i].from_name;
    
    Serial.println("Message from: " + from_name + " (" + chat_id + ")");
    Serial.println("Text: " + text);
    
    // Security: Only respond to authorized user
    if (chat_id != CHAT_ID) {
      Serial.println("⚠️  Unauthorized user! Ignoring.");
      bot.sendMessage(chat_id, "⛔ Unauthorized access");
      continue;
    }
    
    // Only process commands starting with /lights_
    if (!text.startsWith("/lights_")) {
      Serial.println("Not for Lights controller, ignoring.");
      continue;
    }
    
    // Blink LED to show processing
    digitalWrite(STATUS_LED, LOW);
    delay(100);
    digitalWrite(STATUS_LED, HIGH);
    
    // Process commands
    if (text == "/lights_1_on") {
      setLED(1, true);
      bot.sendMessage(chat_id, "✅ Light 1 ON");
      
    } else if (text == "/lights_1_off") {
      setLED(1, false);
      bot.sendMessage(chat_id, "✅ Light 1 OFF");
      
    } else if (text == "/lights_2_on") {
      setLED(2, true);
      bot.sendMessage(chat_id, "✅ Light 2 ON");
      
    } else if (text == "/lights_2_off") {
      setLED(2, false);
      bot.sendMessage(chat_id, "✅ Light 2 OFF");
      
    } else if (text == "/lights_3_on") {
      setLED(3, true);
      bot.sendMessage(chat_id, "✅ Light 3 ON");
      
    } else if (text == "/lights_3_off") {
      setLED(3, false);
      bot.sendMessage(chat_id, "✅ Light 3 OFF");
      
    } else if (text == "/lights_all_on") {
      setLED(1, true);
      setLED(2, true);
      setLED(3, true);
      bot.sendMessage(chat_id, "✅ All lights ON");
      
    } else if (text == "/lights_all_off") {
      setLED(1, false);
      setLED(2, false);
      setLED(3, false);
      bot.sendMessage(chat_id, "✅ All lights OFF");
      
    } else if (text == "/lights_status") {
      String status = "💡 Lights Status:\n";
      status += "Light 1: " + String(led1State ? "ON ✓" : "OFF") + "\n";
      status += "Light 2: " + String(led2State ? "ON ✓" : "OFF") + "\n";
      status += "Light 3: " + String(led3State ? "ON ✓" : "OFF") + "\n";
      status += "WiFi: Connected ✓\n";
      status += "IP: " + WiFi.localIP().toString();
      bot.sendMessage(chat_id, status);
      
    } else if (text == "/lights_help") {
      String help = "💡 Lights Controller Commands:\n\n";
      help += "/lights_1_on - Turn light 1 ON\n";
      help += "/lights_1_off - Turn light 1 OFF\n";
      help += "/lights_2_on - Turn light 2 ON\n";
      help += "/lights_2_off - Turn light 2 OFF\n";
      help += "/lights_3_on - Turn light 3 ON\n";
      help += "/lights_3_off - Turn light 3 OFF\n";
      help += "/lights_all_on - All lights ON\n";
      help += "/lights_all_off - All lights OFF\n";
      help += "/lights_status - Get status\n";
      help += "/lights_help - Show this help";
      bot.sendMessage(chat_id, help);
      
    } else {
      bot.sendMessage(chat_id, "❓ Unknown command. Try /lights_help");
    }
    
    Serial.println("✓ Command processed\n");
  }
}

void setLED(int channel, bool state) {
  int pin;
  const char* name;
  
  switch(channel) {
    case 1:
      pin = LED1_PIN;
      led1State = state;
      name = "Light 1";
      break;
    case 2:
      pin = LED2_PIN;
      led2State = state;
      name = "Light 2";
      break;
    case 3:
      pin = LED3_PIN;
      led3State = state;
      name = "Light 3";
      break;
    default:
      return;
  }
  
  digitalWrite(pin, state ? HIGH : LOW);
  Serial.print("→ ");
  Serial.print(name);
  Serial.println(state ? " ON" : " OFF");
}

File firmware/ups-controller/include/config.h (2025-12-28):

#ifndef CONFIG_H
#define CONFIG_H

// Pin Definitions
#define SERVO_PIN 13
#define STATUS_LED 2

// Servo Settings
#define SERVO_PRESS_ANGLE 90
#define SERVO_REST_ANGLE 0
#define PRESS_DURATION 500  // milliseconds

// Telegram Settings
#define BOT_CHECK_INTERVAL 1000  // Check for messages every 1 second

#endif

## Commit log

2025-12-27 chore: initial project structure
    [UPS_Switch.kicad_pcb, UPS_Switch.kicad_sch]
2025-12-27 feat: add enclosure folder structure
2025-12-28 feat(fw): add Lights controller with Telegram bot integration
    - Controls 3 LED switches via GPIO 25, 26, 27
    - Telegram commands: /lights_1_on, /lights_2_on, /lights_3_on, etc.
    - Same bot as UPS controller, different command prefix
    - Chat ID verification for security
    - Status reporting
2025-12-28 Schematic additions, BoM and outputs next followed by layout
    [UPS_Switch.kicad_pcb, UPS_Switch.kicad_sch]
2025-12-28 BoM assignment
    [UPS_Switch.kicad_sch]
2025-12-28 Layout start
    [UPS_Switch.kicad_pcb, UPS_Switch.kicad_sch, UPS_Switch_BoM.csv]
2025-12-29 layout fixes
    [UPS_Switch.kicad_pcb]
2025-12-29 Updated layout and screengrabs
    [UPS_Switch-B_Cu.gbr, UPS_Switch-B_Mask.gbr, UPS_Switch-B_Paste.gbr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]
2026-01-18 Folder and file renamed
    [PC_and_Light_Controller-B_Cu.gbr, PC_and_Light_Controller-B_Mask.gbr, PC_and_Light_Controller-B_Paste.gbr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]
2026-01-18 Starting enclosure
    [PC_and_Light_Controller.step]
2026-02-01 Manufacturing Readiness
    [PC_and_Light_Controller-B_Cu.gbr, PC_and_Light_Controller-B_Mask.gbr, PC_and_Light_Controller-B_Paste.gbr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]
2026-02-06 Final final manufacturing ready board
    [PC_and_Light_Controller-B_Cu.gbr, PC_and_Light_Controller-B_Mask.gbr, PC_and_Light_Controller-B_Paste.gbr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]
2026-05-10 docs: rewrite README with requirements, architecture diagram, security stance; remove network identifiers; switch to CERN-OHL-P-2.0

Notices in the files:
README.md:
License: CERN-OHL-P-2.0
